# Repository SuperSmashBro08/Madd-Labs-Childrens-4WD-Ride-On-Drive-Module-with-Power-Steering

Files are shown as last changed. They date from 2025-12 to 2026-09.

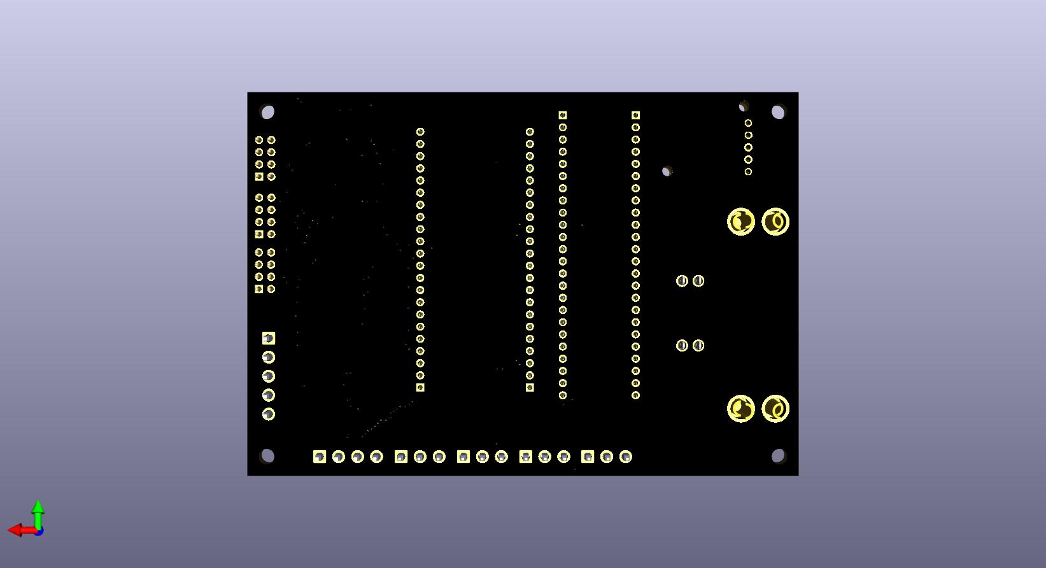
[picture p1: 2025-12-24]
hardware/PCB Files/Kids Ride On PCB Files/Pdfs and images/bottom.jpg

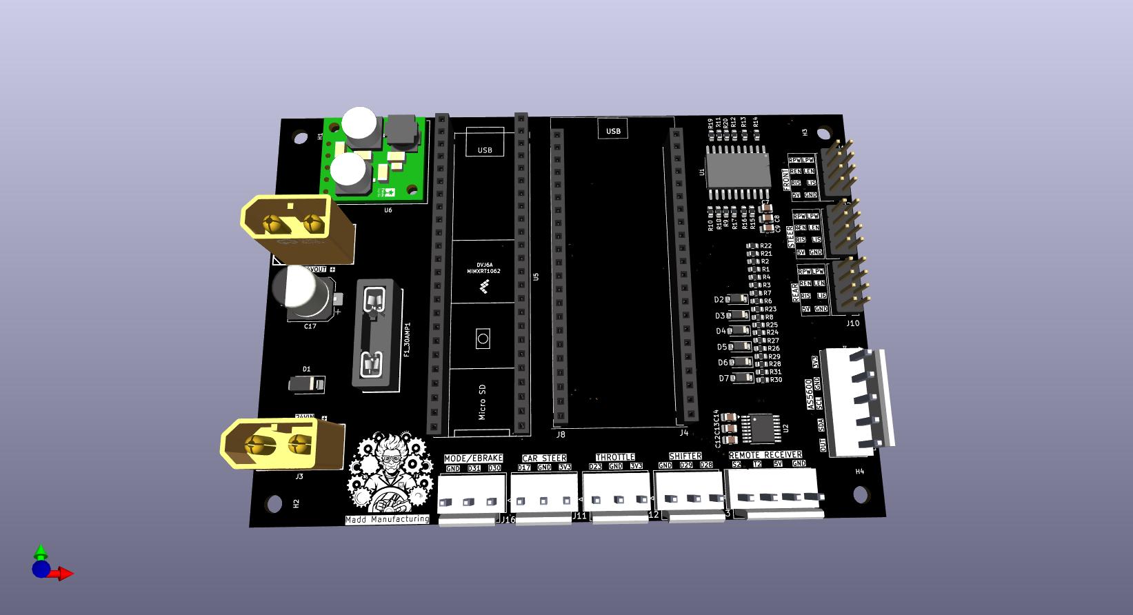
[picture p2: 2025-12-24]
hardware/PCB Files/Kids Ride On PCB Files/Pdfs and images/3d.jpg

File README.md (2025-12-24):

# Kids Ride-On Framework


[]()


An open-source framework for building smart, connected kids' ride-on vehicles with OTA (Over-The-Air) firmware updates, web-based control, and modular peripheral support.

---

## 🎯 Project Overview

This project provides a complete hardware and software framework for upgrading kids' electric ride-on toys with:

- **Dual-MCU Architecture**: ESP32-S3 for WiFi/Web + Teensy 4.1 for real-time control
- **OTA Firmware Updates**: Update both MCUs wirelessly via web browser
- **Web Dashboard**: Monitor and control the vehicle from any device
- **Modular Design**: Easy to add motors, LEDs, sensors, and more
- **Custom PCB**: Purpose-built circuit board for clean integration

---

## 📁 Project Structure

```
Kids-Ride-On-Framework/
├── esp32_flasher/           # ESP32-S3 firmware (WiFi, Web Server, OTA)
│   ├── esp32_flasher.ino    # Main ESP32 code
│   ├── secrets.h.example    # Template for WiFi credentials
│   └── README.md            # ESP32-specific documentation
│
├── teensy_flasherx/         # Teensy 4.1 firmware (Motor control, sensors)
│   ├── teensy_flasherx.ino  # Main application code (YOUR CODE HERE)
│   ├── FlasherXOTA.h/cpp    # OTA update handler (don't modify)
│   ├── FXUtil.h/cpp         # Intel HEX parser (don't modify)
│   ├── FlashTxx.h/c         # Flash primitives (don't modify)
│   └── README.md            # Teensy-specific documentation
│
├── hardware/                # Hardware design files
│   └── PCB/
│       └── Kids Ride On 2.1/
│           ├── Kicad files/ # KiCad schematic and PCB
│           ├── bom/         # Bill of materials
│           ├── 3d/          # 3D models
│           └── Production/  # Gerber files for manufacturing
│
├── Backup/                  # Backup of original firmware
├── readme files/            # Additional documentation
├── .gitignore               # Git ignore rules
└── README.md                # This file
```

---

## 🚀 Getting Started

### Prerequisites

- [Arduino IDE 2.x](https://www.arduino.cc/en/software) or [PlatformIO](https://platformio.org/)
- [Teensyduino](https://www.pjrc.com/teensy/teensyduino.html) add-on for Arduino IDE
- ESP32 Arduino Core (install via Board Manager)

### Hardware Required

- ESP32-S3 DevKitC (or compatible)
- Teensy 4.1
- Custom PCB (see `hardware/PCB/`) or breadboard setup
- 12V/24V power supply (depending on your motors)
- Motors, sensors, LEDs as needed

### Quick Start

1. **Clone the repository**
   ```bash
   git clone https://github.com/yourusername/kids-ride-on-framework.git
   cd kids-ride-on-framework
   ```

2. **Configure WiFi credentials**
   ```bash
   cd esp32_flasher
   cp secrets.h.example secrets.h
   # Edit secrets.h with your WiFi SSID and password
   ```

3. **Upload ESP32 firmware**
   - Open `esp32_flasher/esp32_flasher.ino` in Arduino IDE
   - Select board: ESP32-S3 Dev Module
   - Upload via USB
   - Open Serial Monitor to see the assigned IP address

4. **Upload Teensy firmware**
   - Open `teensy_flasherx/teensy_flasherx.ino` in Arduino IDE
   - Select board: Teensy 4.1
   - Upload via USB (first time only - then use OTA!)

5. **Access the Web Dashboard**
   - Open your browser to the IP address shown in Serial Monitor
   - You can now upload firmware updates wirelessly!

---

## ⚙️ Configuration

### Sensor Calibration (IMPORTANT!)

Every vehicle will have different sensor ranges. Open `teensy_flasherx/teensy_flasherx.ino` and find the **USER CONFIGURATION SECTION** near the top:

```cpp
//******************************************************************************
//                    USER CONFIGURATION SECTION
//******************************************************************************

// ----- STEERING 1 (Primary/Front) -----
#define STEERING1_PIN         A0      // Analog input pin
#define STEERING1_MIN         0       // Raw ADC at full LEFT
#define STEERING1_MAX         1023    // Raw ADC at full RIGHT
#define STEERING1_CENTER      512     // Raw ADC at CENTER

// ----- THROTTLE 1 (Primary) -----
#define THROTTLE1_PIN         A2      // Analog input pin
#define THROTTLE1_MIN         100     // Raw ADC at NO throttle
#define THROTTLE1_MAX         900     // Raw ADC at FULL throttle

// ... more configuration options
```

**How to calibrate:**
1. Upload the firmware with default values
2. Open Serial Monitor
3. Move your steering/throttle and note the raw ADC values
4. Update the MIN/MAX/CENTER values in the code
5. Re-upload (via OTA!)

### WiFi Configuration

For security, WiFi credentials are stored in `secrets.h` which is **not committed to git**.

1. Copy the example file:
   ```bash
   cp esp32_flasher/secrets.h.example esp32_flasher/secrets.h
   ```

2. Edit `secrets.h` with your credentials:
   ```cpp
   #define WIFI_SSID     "YourWiFiName"
   #define WIFI_PASSWORD "YourWiFiPassword"
   ```

---

## 🔧 Hardware

### PCB Design

The custom PCB connects the ESP32-S3 and Teensy 4.1 with proper level shifting and power regulation. Design files are in `hardware/PCB/Kids Ride On 2.1/`.

### Complete Pinout (V2.1 PCB)

#### Teensy 4.1 Pinout

**Analog Inputs (0–3.3V)**
| Pin | Function | Description |
|-----|---|---|
| 17 (A3) | S1_WIPER | Steering Potentiometer |
| 23 (A9) | T1_WIPER | Throttle Potentiometer |
| 16 (A2) | AS5600_OUT | Magnetic Encoder Analog |
| 24 (A10) | STEER_I_L | Steering Motor Current Left |
| 25 (A11) | STEER_I_R | Steering Motor Current Right |
| 26 (A12) | FRONT_I_L | Front Drive Current Left |
| 27 (A13) | FRONT_I_R | Front Drive Current Right |
| 38 (A14) | REAR_I_L | Rear Drive Current Left |
| 39 (A15) | REAR_I_R | Rear Drive Current Right |

**Digital Inputs (3.3V Logic)**
| Pin | Function | Description |
|-----|---|---|
| 28 | SHIFT_FWD | Shifter Forward |
| 29 | SHIFT_REV | Shifter Reverse |
| 30 | MODE_SEL | Mode Select |
| 31 | E_BRAKE | E-Brake Input |

**PWM Outputs (3.3V)**
| Pin | Function | Description |
|-----|---|---|
| 2 | STEER_LPWM | Steering Left PWM |
| 3 | STEER_RPWM | Steering Right PWM |
| 6 | FRONT_LPWM | Front Drive Left PWM |
| 9 | FRONT_RPWM | Front Drive Right PWM |
| 12 | REAR_LPWM | Rear Drive Left PWM |
| 13 | REAR_RPWM | Rear Drive Right PWM |

**Motor Driver Enable (3.3V → 5V via level shifter)**
| Pin | Function | Description |
|-----|---|---|
| 4 | STEER_L_EN | Steering Left Enable |
| 5 | STEER_R_EN | Steering Right Enable |
| 10 | FRONT_L_EN | Front Drive Left Enable |
| 11 | FRONT_R_EN | Front Drive Right Enable |
| 32 | REAR_L_EN | Rear Drive Left Enable |
| 33 | REAR_R_EN | Rear Drive Right Enable |

**I2C (AS5600 Encoder)**
| Pin | Function |
|-----|---|
| 18 | SDA |
| 19 | SCL |

**UART to ESP32-S3**
| Teensy Pin | ESP32 Pin | Function |
|---|---|---|
| 7 (RX2) | GPIO43 (TX) | OTA Flash Data |
| 8 (TX2) | GPIO44 (RX) | OTA Flash Data |
| 14 (TX3) | GPIO18 (RX) | Debug Serial |
| 15 (RX3) | GPIO17 (TX) | Debug Serial |

#### ESP32-S3 Pinout

| GPIO | Function | Description |
|---|---|---|
| 43 | UART TX | TX to Teensy RX2 (Pin 7) |
| 44 | UART RX | RX from Teensy TX2 (Pin 8) |
| 17 | UART TX | TX to Teensy RX3 (Pin 15) |
| 18 | UART RX | RX from Teensy TX3 (Pin 14) |
| 38 | RGB_LED | Status LED / Fiber Optic |

### Bill of Materials

See `hardware/PCB/Kids Ride On 2.1/bom/` for the complete parts list.

---

## 🌐 Web Interface

The ESP32 hosts a web server with:

- **System Status**: Connection status for both MCUs
- **Teensy OTA**: Upload `.hex` files to flash Teensy wirelessly
- **ESP32 OTA**: Upload `.bin` files to update ESP32 wirelessly
- **Serial Monitor**: Real-time serial output from both MCUs

Access via: `http://<ESP32-IP-ADDRESS>/`

---

## 📡 OTA Updates

### Updating Teensy

1. Compile your Teensy code in Arduino IDE
2. Find the `.hex` file in the build folder
3. Open the web dashboard
4. Drag & drop the `.hex` file onto "Flash Teensy 4.1"
5. Wait for completion - Teensy will reboot automatically

### Updating ESP32

1. Export compiled binary from Arduino IDE (Sketch → Export Compiled Binary)
2. Open the web dashboard
3. Drag & drop the `.bin` file onto "ESP32 OTA Update"
4. Wait for completion - ESP32 will reboot automatically

---

## 🛠️ Development

### Adding New Features

All your custom code goes in `teensy_flasherx/teensy_flasherx.ino`:

```cpp
void initPeripherals() {
    // Initialize your motors, LEDs, sensors here
}

void updatePeripherals() {
    // Your main control loop - runs every iteration
    // Read sensors, update motors, etc.
}
```

The FlasherX OTA code is encapsulated and doesn't need modification.

### File Overview

| File | Modify? | Purpose |
|---|---|---|
| `teensy_flasherx.ino` | ✅ YES | Your application code |
| `FlasherXOTA.h/cpp` | ❌ No | OTA update handler |
| `FXUtil.h/cpp` | ❌ No | Intel HEX parser |
| `FlashTxx.h/c` | ❌ No | Low-level flash access |
| `esp32_flasher.ino` | ⚠️ Rarely | Web server & OTA |

---

## 📋 Roadmap

- [x] OTA firmware updates for Teensy 4.1
- [x] OTA firmware updates for ESP32
- [x] Web-based dashboard
- [x] Serial monitor via WebSocket
- [ ] Motor control with acceleration ramping
- [ ] LED strip animations (NeoPixel/WS2812)
- [ ] Steering servo control
- [ ] Speed limiting / parental controls
- [ ] Bluetooth gamepad support
- [ ] Battery monitoring
- [ ] GPS tracking (optional)
- [ ] Mobile app

---

## 🤝 Contributing

Contributions are welcome! Please:

1. Fork the repository
2. Create a feature branch (`git checkout -b feature/amazing-feature`)
3. Commit your changes (`git commit -m 'Add amazing feature'`)
4. Push to the branch (`git push origin feature/amazing-feature`)
5. Open a Pull Request

---

## 📄 License

This project is open source and available under the [MIT License](LICENSE).

---

## ⚠️ Safety Warning

This project involves modifying children's toys with higher-powered electronics. Please:

- Always supervise children when using modified vehicles
- Install appropriate speed limiters
- Use proper fusing and circuit protection
- Test thoroughly in a safe environment
- Follow local regulations for motorized vehicles

---

## 🙏 Acknowledgments

- [FlasherX](https://github.com/joepasquariello/FlasherX) by Joe Pasquariello - Teensy OTA library
- [PJRC](https://www.pjrc.com/) - Teensy development
- [Espressif](https://www.espressif.com/) - ESP32 platform

---

**Happy Building! 🚗💨**

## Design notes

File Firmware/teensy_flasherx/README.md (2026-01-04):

# Teensy 4.1 Kids Ride-On Controller

A comprehensive motor controller firmware for kids' ride-on vehicles featuring dual control modes (steering wheel/pedal and RC remote), safety features, and OTA firmware updates.

## Table of Contents
- [Features](#features)
- [Hardware Overview](#hardware-overview)
- [Control Modes](#control-modes)
- [Safety Features](#safety-features)
- [Configuration Reference](#configuration-reference)
- [Pin Assignments](#pin-assignments)
- [Serial Commands](#serial-commands)
- [OTA Updates](#ota-updates)
- [Troubleshooting](#troubleshooting)

---

## Features

- **Dual Control Modes**: Car mode (steering wheel + pedal) and RC Remote mode (parental override)
- **Rollover Protection**: Speed-based steering limiting and automatic slowdown for sharp turns
- **Soft Stop**: Gradual motor ramp-down to prevent jarring stops on geared motors
- **Encoder Feedback**: Closed-loop steering control using AS5600 magnetic encoder
- **Current Sensing**: Monitor motor current for all 6 motor channels
- **Real-time Telemetry**: Live monitoring via web serial interface
- **OTA Firmware Updates**: Update firmware wirelessly via ESP32-S3 web interface

---

## Hardware Overview

### Microcontroller
- **Teensy 4.1** - 600MHz ARM Cortex-M7
- 10-bit ADC for analog inputs
- I2C for AS5600 encoder
- Multiple UARTs for ESP32 communication

### Motor Drivers (x3)
- **BTS7960** H-Bridge drivers
- Steering motor: Position control with encoder feedback
- Front drive motor: Speed/direction control
- Rear drive motor: Speed/direction control
- 24V power input, 5V enable pins (via level shifter)

### Sensors
- **Steering Pot**: Analog potentiometer on steering column
- **Throttle Pot**: Analog potentiometer on foot pedal
- **AS5600 Encoder**: 12-bit magnetic encoder on steering motor
- **RC Receiver**: PWM signals from RC transmitter

---

## Control Modes

### Mode 1: Car Mode (Default)
The child controls the vehicle using:
- **Steering wheel** → Controls steering motor position
- **Throttle pedal** → Controls front/rear motor speed
- **Shifter** → FWD/REV/NEUTRAL (required for any movement)

**Note**: Steering is disabled in NEUTRAL for safety.

### Mode 2: RC Remote Mode (Parental Override)
The parent takes full control using an RC transmitter:
- **Steer stick (steer2)** → Controls steering (ignores child's steering wheel)
- **Throttle stick (throttle2)** → Controls speed AND direction (ignores shifter)

#### Activating RC Mode
1. Pull RC throttle stick to **full reverse** (≤-90%)
2. **Hold for 3 seconds** → Mode becomes "ARMED"
3. **Release to neutral** → Mode fully activates
4. Serial output: `[RC] *** RC MODE FULLY ACTIVATED ***`

#### Deactivating RC Mode
- Leave **both sticks at neutral** for **20 seconds**
- Mode automatically returns to Car mode
- Serial output: `[RC] *** RC MODE TIMEOUT ***`

**Important**: The "release to neutral" safety prevents accidentally putting the car in reverse when activating RC mode.

---

## Safety Features

### 1. Rollover Protection
Prevents tipping during high-speed turns.

**Part A - Speed-Based Steering Limit:**
| Speed | Max Steering Allowed |
|---|---|
| 0-50% | Full (±100%) |
| 50-80% | Progressively limited |
| 80%+ | Only ±15% |

**Part B - Steering-Based Speed Reduction:**
| Steering Angle | Max Speed Allowed |
|---|---|
| 0-30% | Full (100%) |
| 30-100% | Progressively limited |
| 100% | Only 50% speed |

**How it works**: When you turn sharply, the car slows down FIRST, then allows the turn. This prevents rollovers.

### 2. Soft Stop
Prevents jarring stops when releasing throttle on geared motors.

- Ramps down at **5% per 50ms** (approximately 1 second to stop)
- Acceleration is still immediate (no delay when pressing throttle)
- Direction changes require ramping to zero first

### 3. Neutral Safety
- Steering motor is disabled when shifter is in NEUTRAL
- Prevents unintended steering movement when stationary

### 4. RC Mode Activation Safety
- Requires 3-second hold at full reverse to arm
- Must return to neutral before fully activating
- Prevents accidental reverse when taking control

### 5. RC Mode Timeout
- Automatically returns control to car after 20 seconds of no RC input
- Prevents runaway if parent drops the controller

---

## Configuration Reference

All configurable values are at the top of `teensy_flasherx.ino`.

### Steering Potentiometer (Car's Steering Wheel)
```cpp
#define STEERING_POT_MIN      105     // Raw ADC at full LEFT
#define STEERING_POT_MAX      708     // Raw ADC at full RIGHT  
#define STEERING_POT_CENTER   407     // Raw ADC at CENTER
#define STEERING_POT_DEADZONE 20      // Ignore values within ±20 of center
#define STEERING_INPUT_SMOOTH 15      // Ignore changes < 15% (jitter filter)
#define STEERING_FILTER_ALPHA 0.3     // Low-pass filter (0.0=max filter, 1.0=no filter)
```

### Steering Motor (Encoder-Based Position Control)
```cpp
#define STEER_ANGLE_CENTER    234     // Center angle in degrees
#define STEER_ANGLE_RANGE     45      // ±45° from center (total 90° range)
#define STEER_ANGLE_DEADBAND  15      // Stop motor when within ±15° of target
#define ENCODER_ANGLE_OFFSET  180     // Offset to calibrate encoder zero
```

### Throttle Potentiometer (Foot Pedal)
```cpp
#define THROTTLE_POT_MIN      249     // Raw ADC at NO throttle
#define THROTTLE_POT_MAX      790     // Raw ADC at FULL throttle
#define THROTTLE_POT_DEADZONE 30      // Ignore small values (prevents creep)
```

### RC Receiver (PWM Signals)
```cpp
#define RC_STEER2_PIN         21      // Steering stick input
#define RC_THROTTLE2_PIN      20      // Throttle stick input
```
**Calibrated PWM ranges:**
- Steering: 1065µs (left) → 1500µs (center) → 2000µs (right)
- Throttle: 1000µs (reverse) → 1500µs (neutral) → 2000µs (forward)

### Soft Stop
```cpp
#define SOFT_STOP_RATE        5       // % decrease per step (lower = smoother)
#define SOFT_STOP_INTERVAL    50      // Milliseconds between steps
```
**Tuning**: For slower/smoother stops, decrease RATE to 3 or 2. For faster stops, increase to 8 or 10.

### Rollover Protection
```cpp
#define ROLLOVER_PROTECTION_ENABLED  true   // Master enable (set false to disable)
#define ROLLOVER_SPEED_THRESHOLD     50     // Speed % where limiting starts
#define ROLLOVER_SPEED_FULL_LIMIT    80     // Speed % where max limit applies
#define ROLLOVER_MIN_STEER_RANGE     15     // Min steering % at high speed
#define ROLLOVER_SLOWDOWN_ANGLE      30     // Steer % where speed reduction starts
#define ROLLOVER_SLOWDOWN_FACTOR     50     // Max speed % at full steering
```

**Tuning Guide:**
| Want to... | Adjust |
|---|---|
| Allow more steering at high speed | Increase `ROLLOVER_MIN_STEER_RANGE` |
| Start limiting earlier | Decrease `ROLLOVER_SPEED_THRESHOLD` |
| Slow down more for turns | Decrease `ROLLOVER_SLOWDOWN_FACTOR` |
| Start slowing earlier | Decrease `ROLLOVER_SLOWDOWN_ANGLE` |

### Motor Configuration
```cpp
#define MOTOR_PWM_FREQ        20000   // PWM frequency (Hz)
#define MOTOR_MAX_SPEED       255     // Max PWM value (0-255)
```

---

## Pin Assignments

### Analog Inputs
| Pin | Function |
|-----|---|
| 17 (A3) | Steering Pot |
| 23 (A9) | Throttle Pot |
| 20 (A6) | RC Throttle2 |
| 21 (A7) | RC Steer2 |
| 24-27, 38-39 | Current Sensors |

### Digital Inputs
| Pin | Function |
|-----|---|
| 28 | Shifter Reverse |
| 29 | Shifter Forward |
| 30 | Mode Select |
| 31 | E-Brake |

### PWM Outputs (Motor Drivers)
| Pins | Motor |
|---|---|
| 2, 3 | Steering LPWM/RPWM |
| 6, 9 | Front LPWM/RPWM |
| 12, 13 | Rear LPWM/RPWM |

### Enable Outputs (via Level Shifter)
| Pins | Motor |
|---|---|
| 4, 5 | Steering L_EN/R_EN |
| 10, 11 | Front L_EN/R_EN |
| 32, 33 | Rear L_EN/R_EN |

### I2C (Encoder)
| Pin | Function |
|-----|---|
| 18 | SDA |
| 19 | SCL |

### UART (ESP32)
| Pins | Function |
|---|---|
| 7, 8 | Serial2 (OTA Flash) |
| 14, 15 | Serial3 (Telemetry) |

---

## Serial Commands

Connect via USB Serial at 115200 baud.

| Command | Description |
|---|---|
| `help` | Show all commands |
| `status` | Show system status |
| `version` | Show firmware version |
| `telem` or `t` | Toggle telemetry on/off |
| `header` or `h` | Print telemetry header |
| `verbose` or `v` | Verbose telemetry mode |
| `compact` or `c` | Compact telemetry mode |
| `rate <ms>` | Set telemetry rate (10-1000ms) |
| `rctest` or `rc` | Test RC receiver PWM signals |
| `calenc` or `ce` | Encoder calibration helper |

---

## Telemetry Output

The telemetry displays real-time data in the web serial monitor:

```
|------- RAW INPUTS ------|--- PROCESSED (%) ---|-- PWM OUTPUTS --|--- CURRENT ---|SOURCE|-- SYS --|
| Steer Throt Str2  Thr2  Encdr | Steer Throt Str2  Thr2  | StL  StR  FrL  FrR  ReL  ReR| ...      |      | Loop  T |
```

**Columns:**
- **RAW INPUTS**: Steering pot, Throttle pot, RC steer, RC throttle, Encoder angle
- **PROCESSED**: Converted to -100% to +100% or 0-100%
- **PWM OUTPUTS**: Current PWM values for all 6 motor channels
- **CURRENT**: Motor current in mA (if sensors calibrated)
- **SOURCE**: "Car" or "Remot" (which input is active)
- **SYS**: Loop time (µs) and CPU temperature

---

## OTA Updates

Firmware can be updated wirelessly via the ESP32-S3 web interface.

### How It Works
1. ESP32 hosts a web page with file upload
2. User uploads `.hex` file from Arduino IDE
3. ESP32 sends firmware to Teensy via Serial2
4. Teensy writes to flash buffer and reboots

### To Generate .hex File
In Arduino IDE: Sketch → Export Compiled Binary

---

## Troubleshooting

| Issue | Solution |
|---|---|
| Motors don't move | Check EN pins going HIGH, verify shifter not in NEUTRAL |
| Steering oscillates | Increase `STEER_ANGLE_DEADBAND`, check encoder wiring |
| Steering jitters | Increase `STEERING_INPUT_SMOOTH`, decrease `STEERING_FILTER_ALPHA` |
| RC mode won't activate | Hold throttle full reverse 3+ seconds, then release to neutral |
| Car tips over in turns | Decrease `ROLLOVER_MIN_STEER_RANGE` and `ROLLOVER_SLOWDOWN_FACTOR` |
| Stops too abruptly | Decrease `SOFT_STOP_RATE` to 2 or 3 |
| RC reading 0 | Use `rctest` command to check PWM signals, verify wiring |

---

## Version History

- **1.5.3** - Rollover protection, soft stop, RC mode improvements
- **1.5.x** - RC receiver PWM support, source display
- **1.4.x** - Encoder-based steering control
- **1.3.x** - Initial motor control implementation

---

## License

This project is open source. See LICENSE file for details.

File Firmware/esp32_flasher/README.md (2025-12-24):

# ESP32-S3 Teensy 4.1 FlasherX Web Interface

A web-based firmware upload system for programming Teensy 4.1 via an ESP32-S3 using the FlasherX protocol.

## Features

- **Teensy 4.1 Flashing**: Upload .hex/.bin firmware files via FlasherX protocol
- **ESP32 OTA Updates**: Update the ESP32 firmware over-the-air
- **Web Interface**: Modern responsive UI at http://192.168.1.29
- **Upload Progress Bar**: Real-time progress indication
- **Error Reporting**: Clear error messages for troubleshooting
- **Serial Monitor**: Live serial output from both ESP32 and Teensy via WebSocket

## Hardware Requirements

- ESP32-S3 DevKit
- Teensy 4.1
- Custom PCB with pre-wired UART connections

## Custom PCB Wiring

### Flashing UART (ESP32 UART0 ↔ Teensy Serial2)
Used for firmware upload via FlasherX protocol.

| ESP32-S3 Pin | Teensy 4.1 Pin | Function |
|---|---|---|
| GPIO 43 (TX0) | RX2 (Pin 7) | ESP32 TX → Teensy RX |
| GPIO 44 (RX0) | TX2 (Pin 8) | ESP32 RX ← Teensy TX |

### Debug UART (ESP32 UART1 ↔ Teensy Serial3)
Used for serial monitoring in web interface.

| ESP32-S3 Pin | Teensy 4.1 Pin | Function |
|---|---|---|
| GPIO 17 | RX3 (Pin 15) | ESP32 TX → Teensy RX |
| GPIO 18 | TX3 (Pin 14) | ESP32 RX ← Teensy TX |

### Control Pins
| ESP32-S3 Pin | Teensy 4.1 Pin | Function |
|---|---|---|
| GPIO 4 | Reset | Reset control |
| GPIO 5 | Program | Program mode |
| GND | GND | Ground |

## Configuration

Edit the following in `esp32_flasher.ino`:

```cpp
const char* ssid = "YOUR_SSID";
const char* password = "YOUR_PASSWORD";
```

## Arduino IDE Setup

### Board Manager
1. Add ESP32 board URL: `https://raw.githubusercontent.com/espressif/arduino-esp32/gh-pages/package_esp32_index.json`
2. Install "ESP32 by Espressif Systems"

### Library Dependencies
Install via Library Manager:
- **ArduinoJson** by Benoit Blanchon (v6.x)
- **WebSockets** by Markus Sattler

### Board Settings
- Board: "ESP32S3 Dev Module"
- USB Mode: "USB-OTG (TinyUSB)"
- Partition Scheme: "Default 4MB with spiffs"
- Upload Speed: 921600

## Usage

1. Upload this sketch to ESP32-S3
2. Open Serial Monitor (115200 baud) to see connection status
3. Navigate to http://192.168.1.29 in your browser
4. Use the web interface to:
   - Upload Teensy firmware (.hex or .bin files)
   - Update ESP32 firmware via OTA (.bin files)
   - Monitor serial output from both devices
   - Reset Teensy remotely

## FlasherX Protocol

The Teensy must have the FlasherX receiver sketch loaded. The protocol uses:
- **Flash Serial (Serial2)**: Firmware data transfer
- **Debug Serial (Serial3)**: Status messages to web monitor

Protocol commands:
- Sync: Send 0x55 bytes, receive ACK (0x06)
- Block: Send address + data + checksum, receive ACK
- Finish: Send finish command, receive ACK

## Troubleshooting

| Issue | Solution |
|---|---|
| WiFi won't connect | Check SSID/password, verify 2.4GHz network |
| FlasherX sync fails | Verify wiring, check Teensy has receiver sketch |
| Upload progress stuck | Check serial connection speed (115200 baud) |
| WebSocket disconnects | Refresh page, check network stability |

## LED Indicators (Web UI)

- 🟢 Green: Connected/Success
- 🔴 Red: Disconnected/Error
- 🔵 Blue: In Progress

## API Endpoints

| Endpoint | Method | Description |
|---|---|---|
| `/` | GET | Web interface |
| `/status` | GET | System status JSON |
| `/teensy/upload` | POST | Upload Teensy firmware |
| `/teensy/reset` | POST | Reset Teensy |
| `/esp/ota` | POST | ESP32 OTA update |

WebSocket on port 81 for real-time serial monitoring.

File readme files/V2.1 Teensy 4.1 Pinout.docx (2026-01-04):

# Kids Ride-On V3 – Teensy 4.1 & ESP32-S3 Pinout

## Teensy 4.1 Pinout

### Analog Inputs (0–3.3V)

- Pin 17 (A3) – Steering Pot (S1_WIPER)
- Pin 23 (A9) – Throttle Pot (T1_WIPER)
- Pin 16 (A2) – AS5600 Analog Out
- Pin 24 (A10) – Steer Motor Current L
- Pin 25 (A11) – Steer Motor Current R
- Pin 26 (A12) – Front Drive Current L
- Pin 27 (A13) – Front Drive Current R
- Pin 38 (A14) – Rear Drive Current L
- Pin 39 (A15) – Rear Drive Current R

### Digital Inputs (3.3V Logic)

- Pin 28 – Shifter Forward
- Pin 29 – Shifter Reverse
- Pin 30 – Mode Select
- Pin 31 – E-Brake Input

### PWM Outputs (3.3V)

- Pin 2 – Steering LPWM
- Pin 3 – Steering RPWM
- Pin 6 – Front Drive LPWM
- Pin 9 – Front Drive RPWM
- Pin 12 – Rear Drive LPWM
- Pin 13 – Rear Drive RPWM

### Motor Driver Enable Outputs (3.3V → 5V)

- Pin 4 – Steering L_EN
- Pin 5 – Steering R_EN
- Pin 10 – Front Drive L_EN
- Pin 11 – Front Drive R_EN
- Pin 32 – Rear Drive L_EN
- Pin 33 – Rear Drive R_EN

### I2C

- Pin 18 – SDA
- Pin 19 – SCL

### UART Links to ESP32-S3

- Pin 8 (TX2) → ESP32 GPIO44
- Pin 7 (RX2) ← ESP32 GPIO43
- Pin 14 (TX3) → ESP32 GPIO18
- Pin 15 (RX3) ← ESP32 GPIO17

## ESP32-S3 Used Pins

- GPIO44 – UART RX from Teensy TX2
- GPIO43 – UART TX to Teensy RX2
- GPIO18 – UART RX from Teensy TX3
- GPIO17 – UART TX to Teensy RX3
- GPIO38 – RGB / Fiber Optic Status Indicator

## Remote Control Pins 5V

- GPIO 20 – Steering2
- GPIO 21 –Throttle2

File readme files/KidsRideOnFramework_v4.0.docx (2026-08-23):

# MAD LABS – Kids Ride-On 24 V Control System

## Architecture & Safety Framework

Project: Kids Ride-On 24 V 4WD

Maintainer: MAD Labs / MAD Manufacturing

Baseline Version: v4.0

Status: Active / Living Document

## 1. Purpose of This Document

This file defines the high-level architecture, responsibilities, and safety philosophy of the MAD Labs Kids Ride-On control system.

It is intentionally implementation-agnostic: - No firmware code - No low-level wiring diagrams - No PCB schematics

Those details live elsewhere (pinout docs, KiCad, firmware repos).

This document answers: - What each subsystem does - How power and control are structured - Where safety decisions are made - Why the system is designed this way

This is a living, append-only framework. New safety features or behavioral rules are added as sections, not replacements.

## 2. Power Architecture

- 24 V Battery Input
  - Primary system power
  - Routed directly to all motor drivers
- Logic Power (5 V)
  - Derived from 24 V via buck converter
  - Supplies:
    - Teensy 4.1
    - ESP32-S3
    - Motor driver logic pins
- Separation of Domains
  - High-current motor power remains isolated from logic control
  - Logic ground is common-reference only

## 3. Controller Roles & Separation of Concerns

### 3.1 Teensy 4.1 — Real-Time Control Controller

The Teensy 4.1 is the authoritative control brain of the vehicle.

Responsibilities: - All PWM motor control - All sensor acquisition - All safety logic - Closed-loop steering control - Soft-start / soft-stop behavior - Speed vs steering angle limiting - Fault detection and response

All sensors connect directly to the Teensy.

No safety-critical decision depends on the ESP32.

### 3.2 ESP32-S3 — OTA & Monitoring Hub

The ESP32-S3 exists to remove the need for physical access to the system.

Responsibilities: - Over-the-air firmware updates (ESP32 + Teensy) - High-speed serial monitoring - Web / OTA hub connectivity - System status indication (RGB)

The ESP32 does not: - Generate PWM - Read safety sensors - Make motion decisions

A failure of the ESP32 does not prevent safe vehicle operation.

## 4. Inter-Processor Communication

- Two dedicated UART links between Teensy and ESP32
  - UART A: Teensy firmware flashing
  - UART B: High-speed telemetry / logging
- ESP32 acts as:
  - Uploader
  - Bridge
  - Monitor

## 5. Motor Control Architecture

Three independent motor groups are controlled via BTS7960 drivers:

### 5.1 Steering Motor

- Electrically actuates steering
- Closed-loop control using magnetic encoder feedback
- Software-defined soft limits

### 5.2 Front Drive Motors

- Both front wheels driven together
- Current sensing monitored
- PWM speed control

### 5.3 Rear Drive Motors

- Both rear wheels driven together
- Current sensing monitored
- PWM speed control

All motor groups: - Use PWM for speed - Use enable pins for safety gating - Are monitored for overcurrent conditions

## 6. Sensors & User Inputs

### 6.1 Magnetic Steering Encoder

- Absolute angle measurement
- Used for:
  - Closed-loop steering
  - Steering angle limits
  - Speed to Steering Angle-based safety reduction

### 6.2 Throttle Input

- Analog potentiometer
- Represents user-requested speed

### 6.3 Steering Input

- Analog potentiometer
- User-requested steering direction

### 6.4 Shifter

- Neutral / Forward / Reverse
- Neutral enforced during fault conditions

### 6.5 Mode / E-Brake (Reserved)

- Future expansion input
- Intended for advanced safety or braking modes.. but this is not actually implemented in code and can be used for anything you desire ie does not have to be for e-brake or mode

### 6.6 Remote Control (Parental Override)

- Allows adult takeover of vehicle control

Takeover Procedure: 1. Hold Down + Reverse for 3 seconds 2. Return controls to neutral 3. Remote gains control 4. Control auto-releases after 20 seconds of inactivity

## 7. Motion Behavior & Safety Logic

### 7.1 Soft Start / Soft Stop

- Acceleration is ramped
- Deceleration is ramped
- Prevents sudden jolts
- Reduces drivetrain stress
- Must include during Takeover Procedure(prevents sudden stop on takeover if vehicle is moving fast)

### 7.2 Steering Angle vs Speed Limiting

- Maximum steering angle decreases as speed increases
- If a sharp steering angle is requested:
  - Vehicle speed is reduced first
  - Steering is then allowed

This reduces rollover risk but does not eliminate it.

## 8. System Status Indicator

### RGB Indicator (ESP32 GPIO38)

- Fiber-optic RGB output
- Always illuminated

Indicator States: - RED (Default) - ESP32 not connected - Teensy not responding - OTA server unavailable

- GREEN pulsing
  - ESP32 online
  - Teensy responding
  - OTA server reachable
- BLUE pulsing
  - OTA Updating in Progress

This provides an immediate visual health indicator.

## 9. Connector Philosophy (High Level)

- Motor drivers use multi-pin locking connectors
- Sensors use grouped, keyed connectors
- Future expansion ports are reserved and documented

Exact pin mappings are defined in the PCB pinout documentation.

## 10. Failure Modes & Responses (Why This Exists)

This section is intentionally high-level.

It does not list every fault condition.

Instead, it defines the rule:

Any detected fault must move the system to a safer state than it was previously in.

Examples: - Loss of Steering1 or angle sense feedback → cut Throttle1 - Overcurrent detected → reduce PWM or disable output - Invalid input state → force neutral

As new safety behaviors are added, they are appended here as subsections.

## 11. Living Document Policy

- This file is versioned in GitHub
- New features append sections
- Existing sections are not rewritten without version notes

This creates a clear historical record of why the system behaves the way it does.

End of Baseline Framework (v4.0)

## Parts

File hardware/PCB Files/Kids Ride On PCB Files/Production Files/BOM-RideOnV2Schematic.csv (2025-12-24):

Comment | Designator | Footprint | LCSC | Quantity
0R | R32 | R_0805_2012Metric | C100045 | 1
3.3k | R24,R26,R28,R30,R7,R8 | R_0603_1608Metric | C108078 | 6
33R | R1,R15,R16,R17,R18,R19,R2,R20,R21,R22,R3,R4 | R_0603_1608Metric | C108661 | 12
10uF | C14,C9 | C_0805_2012Metric | C15850 | 2
Conn_01x03 | J11,J12,J13,J16 | JST_VH_B3P-VH-B_1x03_P3.96mm_Vertical | C160316 | 4
Conn_01x04 | J5 | JST_VH_B4P-VH-B_1x04_P3.96mm_Vertical | C160317 | 1
Conn_01x05 | J7 | JST_VH_B5P-VH-B_1x05_P3.96mm_Vertical | C160318 | 1
1.8k | R23,R25,R27,R29,R31,R6 | R_0603_1608Metric | C185354 | 6
SN74AHCT244 | U1 | SOIC-20_L12.8-W7.5-P1.27-LS10.3-BL | C2675568 | 1
1uF | C13,C8 | C_0805_2012Metric | C28323 | 2
Conn_01x24 | J6,J9 | PinSocket_1x24_P2.54mm_Vertical | C2883741 | 2
Conn_02x04_Odd_Even | J1,J10,J2 | PinHeader_2x04_P2.54mm_Vertical | C32713277 | 3
Fuse | F1_30AMP1 | FUSE-TH_4P-L19.8-W6.7_3557-2 | C352820 | 1
CD74HC4050 | U2 | TSSOP-16_4.4x5mm_P0.65mm | C352825 | 1
SMAJ33A | D1 | D_SMA | C353454 | 1
3.4V | D2,D3,D4,D5,D6,D7 | D_SOD-123 | C48587220 | 6
100nF | C12,C7 | C_0805_2012Metric | C49678 | 2
220uF/35V | C17 | CP_Elec_8x10.5 | C5246556 | 1
Conn_01x22 | J4,J8 | PinSocket_1x22_P2.54mm_Vertical | C7499337 | 2
10k | R10,R11,R12,R13,R14,R9 | R_0603_1608Metric | C98220 | 6
XT60-M. | J15,J3 | CONN-TH_XT60 | C98733 | 2
D24V50F5 | U6 | D24V50F5 |  | 1

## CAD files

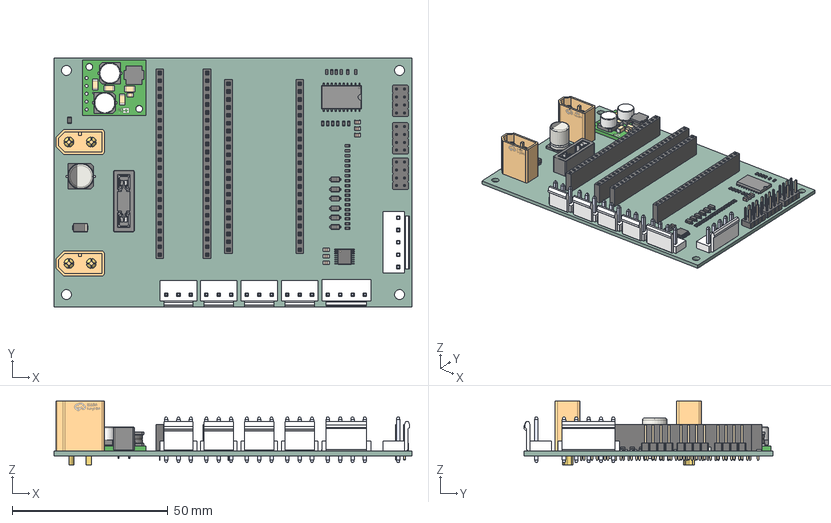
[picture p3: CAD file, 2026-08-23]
hardware/PCB Files/Kids Ride On PCB Files/3d/RideOnSchematic.step
115.0 x 80.0 x 20.5 mm
R_0603_1608Metric x 30
d24v50f5-step-down-voltage-regulator
C_0805_2012Metric x 6
PinHeader_2x04_P2.54mm_Vertical x 3
D_SOD-123 x 6
BxP-VH_4
pin x 4
R_0805_2012Metric
CP_Elec_8x10.5
TSSOP-16_4.4x5mm_P0.65mm
PinSocket_1x24_P2.54mm_Vertical x 2
FUSE-TH_4P-L19.8-W6.7_3557-2
CONN-TH_XT60 x 2
B3P-VH(LF)(SN)_B3P-VH(LF)(SN) x 4
SOIC-20_L12.8-W7.5-P1.27-LS10.3-BL
D_SMA
PinSocket_1x22_P2.54mm_Vertical x 2
B5P-VH-LF--SN---3DModel-STEP-269445
RideOnV2Schematic_PCB

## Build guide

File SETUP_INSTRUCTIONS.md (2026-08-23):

# Kids Custom Power Wheels Project - Setup Instructions

## Table of Contents
1. [Required Parts & Tools](#required-parts--tools)
2. [Firmware Setup](#firmware-setup)
3. [Hardware Assembly](#hardware-assembly)
4. [Wiring Guide](#wiring-guide)
5. [First Power-Up](#first-power-up)

---

## Required Parts & Tools

### Electronics
| Qty | Part | Description |
|-----|---|---|
| 1 | Teensy 4.1 | Main microcontroller |
| 1 | ESP32-S3 DevKitC-1 (N8R8) | WiFi/Web server controller from Espressif |
| 3 | BTS7960 Motor Driver Modules | High-current H-bridge motor drivers (Steering, Front, Rear) |
| 1 | Pololu D24V50F5 | 5V 5A Step-down voltage regulator |
| 1 | AS5600 Encoder Module | Magnetic rotary encoder for steering feedback |
| 1 | FlySky FS-i6X | RC controller with receiver |
| 1 | Custom PCB | Main control board |

### Connectors & Hardware
| Qty | Part | Description |
|-----|---|---|
| 4 | XT60E-M | Panel mount male connectors |
| 6 | XT60 Female | Female bullet connectors |
| 8 | JST-VH 3.96mm 3-pin Female | For BTS7960 signal connections |
| 4 | JST-VH 3.96mm 3-pin Male | Mating connectors |
| 2 | JST-VH 3.96mm 4-pin Female | For additional connections |
| 1 | JST-VH 3.96mm 4-pin Male | Mating connector |
| 2 | JST-VH 3.96mm 5-pin Female | For receiver connection |
| 1 | JST-VH 3.96mm 5-pin Male | Mating connector |
| 1 | 30-40A Blade Fuse | Main power protection |
| 6 | M3x20mm Standoffs | PCB mounting (or 3D printed) |
| - | M3 Screws | Various lengths for assembly |
| - | M2.5 Screws | For XT60E-M connector mounting |
| - | Spade Connectors | For shifter connections |
| - | Dupont Connector Assortment | For misc connections |
| - | Heat Shrink Assortment | Wire insulation |

### Wire
| Qty | Part | Description |
|-----|---|---|
| - | 16 AWG Red Wire | Power positive connections |
| - | 16 AWG Black Wire | Power ground connections |

### Controls
| Qty | Part | Description |
|-----|---|---|
| 1 | Foot Pedal Potentiometer | Throttle control (Amazon) |
| 1 | Waterproof Potentiometer | Steering wheel feedback |
| 1-2 | 3-Way Rocker Switch | For shifter (if not using existing) |

### Tools Required
- Soldering station
- Wire cutters/strippers
- Crimping tools (for JST and Dupont connectors)
- Screwdrivers
- Multimeter (recommended)

---

## Firmware Setup

### Step 1: Configure WiFi Credentials

1. Navigate to the `Firmware/esp32_flasher/` folder
2. Open the `secrets.h` file
3. Add your WiFi network credentials:

```cpp
#define WIFI_SSID "YourWiFiNetworkName"
#define WIFI_PASSWORD "YourWiFiPassword"
```

4. Save the file

### Step 2: Flash the ESP32-S3

1. Connect the ESP32-S3 DevKitC-1 to your computer via USB
2. Open the Arduino IDE (or PlatformIO)
3. Select the correct board: **ESP32-S3 Dev Module**
4. Select the correct COM port
5. Open `Firmware/esp32_flasher/esp32_flasher.ino`
6. Click **Upload** to flash the firmware
7. **Important:** Open the Serial Monitor and set the baud rate to **115200**
8. The ESP32 will display its IP address once connected to your WiFi network
9. **Write down this IP address** - you will need it to access the web server

### Step 3: Flash the Teensy 4.1

1. Connect the Teensy 4.1 to your computer via USB
2. Open the Arduino IDE with Teensyduino installed
3. Select board: **Teensy 4.1**
4. Select the correct COM port
5. Open `Firmware/teensy_flasherx/teensy_flasherx.ino`
6. Click **Upload** to flash the firmware
7. Wait for the upload to complete

### Step 4: Access the Web Server

1. Open a web browser on a device connected to the same WiFi network
2. Type the IP address from Step 2 into the browser address bar
3. The web interface should load, allowing you to configure and control the system

---

## Hardware Assembly

### PCB Mounting

1. Install the 6x M3x20mm standoffs (or 3D printed standoffs) to mount the custom PCB in the enclosure
2. Secure with M3 screws

### Install the Fuse

1. Insert the **30-40A blade fuse** into the fuse slot on the custom PCB
2. Ensure it is fully seated

### Install the Voltage Regulator

1. Mount the Pololu D24V50F5 step-down regulator to the designated location on the PCB
2. This converts the 24-27V input to 5V for the control electronics

### Install Microcontrollers

1. Plug the **Teensy 4.1** into its designated socket on the custom PCB
2. Plug the **ESP32-S3 DevKitC-1** into its designated socket on the custom PCB
3. Ensure both are properly oriented and fully seated

### Mount XT60E-M Connectors

1. Install the 4x XT60E-M panel mount connectors in the enclosure
2. Secure with M2.5 screws

---

## Wiring Guide

### Power Input

1. Connect **24V to 27V** power source to the main power input
2. Use 16 AWG wire for all power connections
3. **Red = Positive (+)**
4. **Black = Negative/Ground (-)**

### BTS7960 Motor Driver Wiring

You have **3x BTS7960 modules** controlling:
- **Steering Motor**
- **Front Drive Motor**
- **Rear Drive Motor**

#### Power Connections (for each BTS7960):
| BTS7960 Pin | Connection |
|---|---|
| B+ | 24-27V Positive (from PCB power out) |
| B- | Ground (from PCB power out) |
| M+ | Motor Positive |
| M- | Motor Negative |

Use **16 AWG red and black wire** for all power in/out connections to the BTS7960 modules.

#### Signal Connections (8-pin JST):

Each BTS7960 module has an 8-pin signal connection to the custom PCB.

**The pins are clearly labeled on both the BTS7960 module and the custom PCB - simply match the labels:**

| Pin | Signal |
|-----|---|
| RPWM | Right PWM |
| LPWM | Left PWM |
| R_EN | Right Enable |
| L_EN | Left Enable |
| R_IS | Right Current Sense |
| L_IS | Left Current Sense |
| VCC | 5V Logic |
| GND | Ground |

Use the 3-pin JST-VH connectors to connect from the custom PCB to each BTS7960 module.

### FlySky Receiver Wiring

Connect the FlySky receiver to the custom PCB using the JST connector:

| Receiver Pin | PCB Connection |
|---|---|
| 5V (VCC) | 5V |
| GND | GND |
| CH1 (Steering) | Steering Signal Pin |
| CH2 (Throttle) | Throttle Signal Pin |

### AS5600 Encoder Wiring

Connect the AS5600 magnetic encoder module for steering position feedback according to the PCB pinout.

### Shifter Wiring

**If your Power Wheels has an existing shifter:**
- Connect the shifter contacts to the PCB using spade connectors

**If you need to build a shifter:**
- Use 2x 3-way rocker switches
- Wire to provide Forward/Neutral/Reverse selection

### Throttle Pedal

Connect the foot pedal potentiometer:
- VCC → 5V
- GND → Ground  
- Signal → Throttle ADC input

### Steering Wheel Potentiometer

Connect the waterproof potentiometer on the steering wheel:
- VCC → 5V
- GND → Ground
- Signal → Steering ADC input

---

## First Power-Up

### Pre-Power Checklist

- [ ] All wiring double-checked
- [ ] Fuse installed (30-40A)
- [ ] Both Teensy and ESP32 are flashed and installed
- [ ] BTS7960 modules connected (power and signal)
- [ ] FlySky receiver connected
- [ ] Motors connected to BTS7960 outputs
- [ ] No loose wires or short circuits

### Power On Sequence

1. Ensure the FlySky transmitter is **OFF**
2. Apply **24-27V** power to the system
3. Wait for the ESP32 to boot and connect to WiFi
4. Open Serial Monitor at **115200 baud** to verify IP address (if needed)
5. Access the web interface via the IP address in your browser
6. Turn on the FlySky transmitter
7. Verify communication in the web interface
8. Test each function at low power before full operation

### Troubleshooting

| Issue | Solution |
|---|---|
| No IP address displayed | Check WiFi credentials in `secrets.h` |
| Web server not loading | Ensure device is on same network, check IP address |
| Motors not responding | Check BTS7960 wiring, verify 8-pin signal connections |
| No RC signal | Verify FlySky receiver wiring, check binding |
| System not powering on | Check fuse, verify voltage (24-27V) |

---

## Safety Warnings

⚠️ **CAUTION:** This system operates at high currents. Always:
- Use appropriately rated wire (16 AWG minimum for power)
- Install the fuse before first power-up
- Double-check polarity before connecting power
- Supervise children at all times during operation
- Test in a safe, open area

---

## Support

For questions, issues, or contributions, please open an issue on the GitHub repository.

**Happy Building!** 🚗⚡

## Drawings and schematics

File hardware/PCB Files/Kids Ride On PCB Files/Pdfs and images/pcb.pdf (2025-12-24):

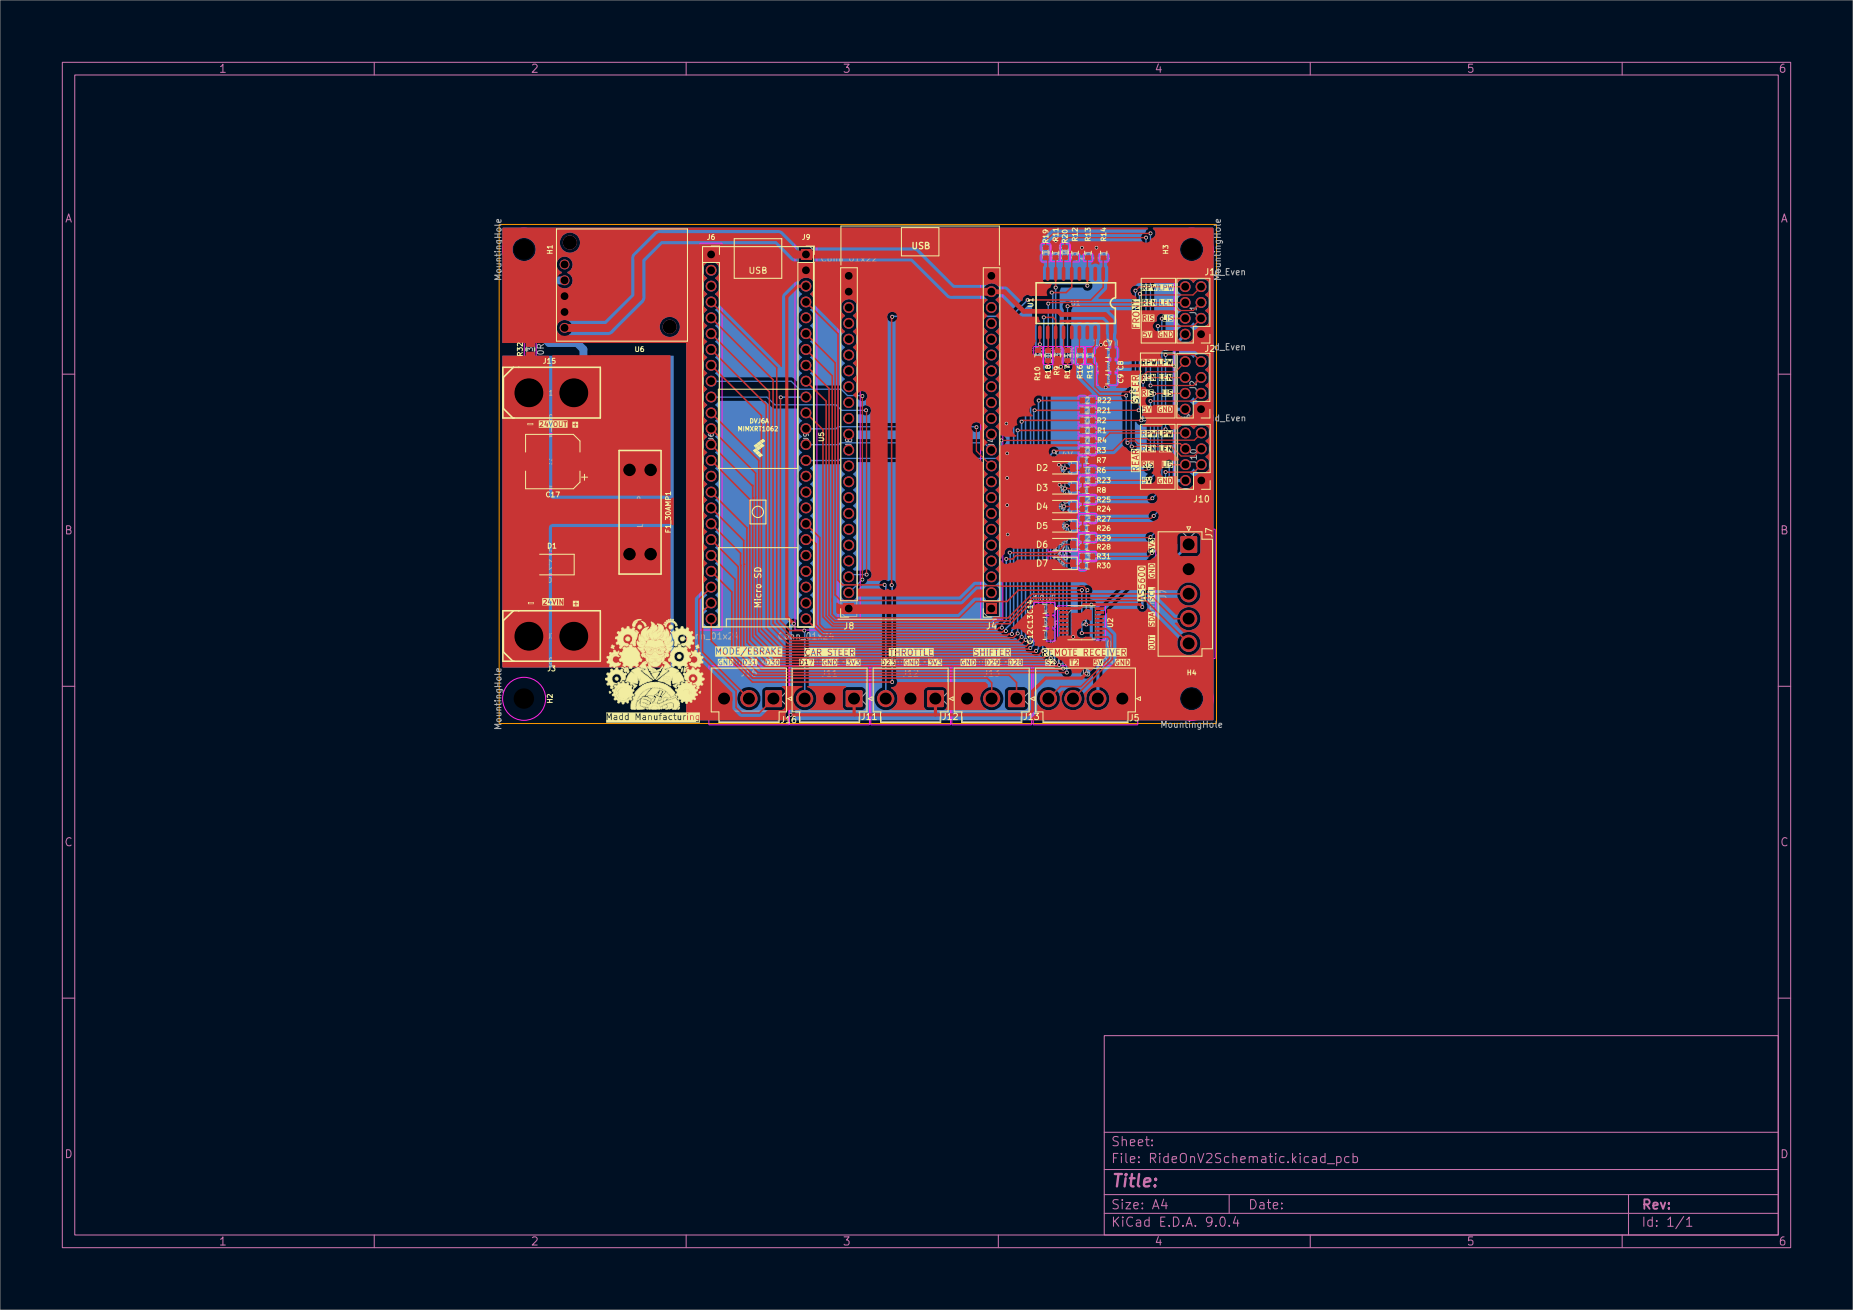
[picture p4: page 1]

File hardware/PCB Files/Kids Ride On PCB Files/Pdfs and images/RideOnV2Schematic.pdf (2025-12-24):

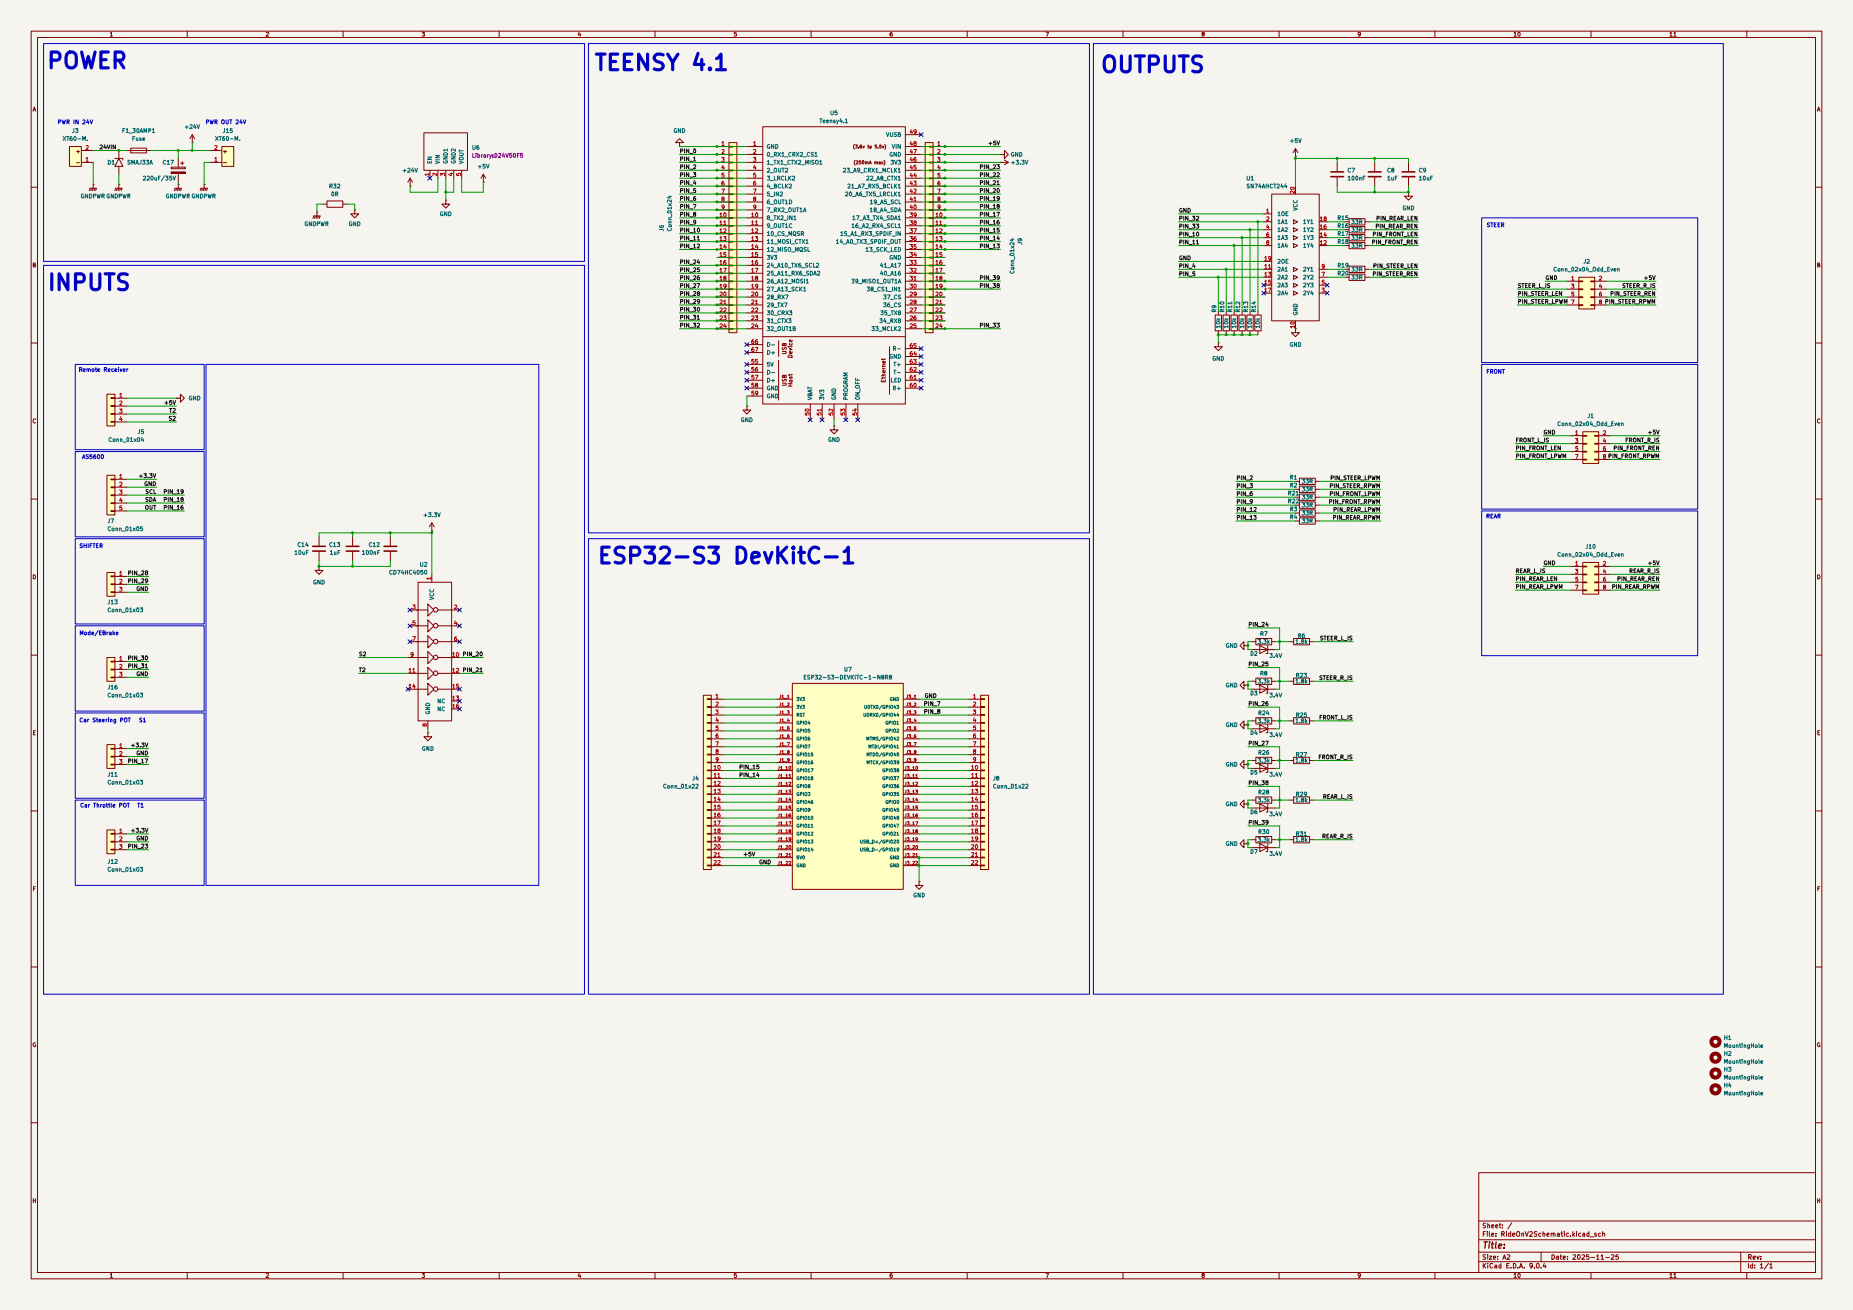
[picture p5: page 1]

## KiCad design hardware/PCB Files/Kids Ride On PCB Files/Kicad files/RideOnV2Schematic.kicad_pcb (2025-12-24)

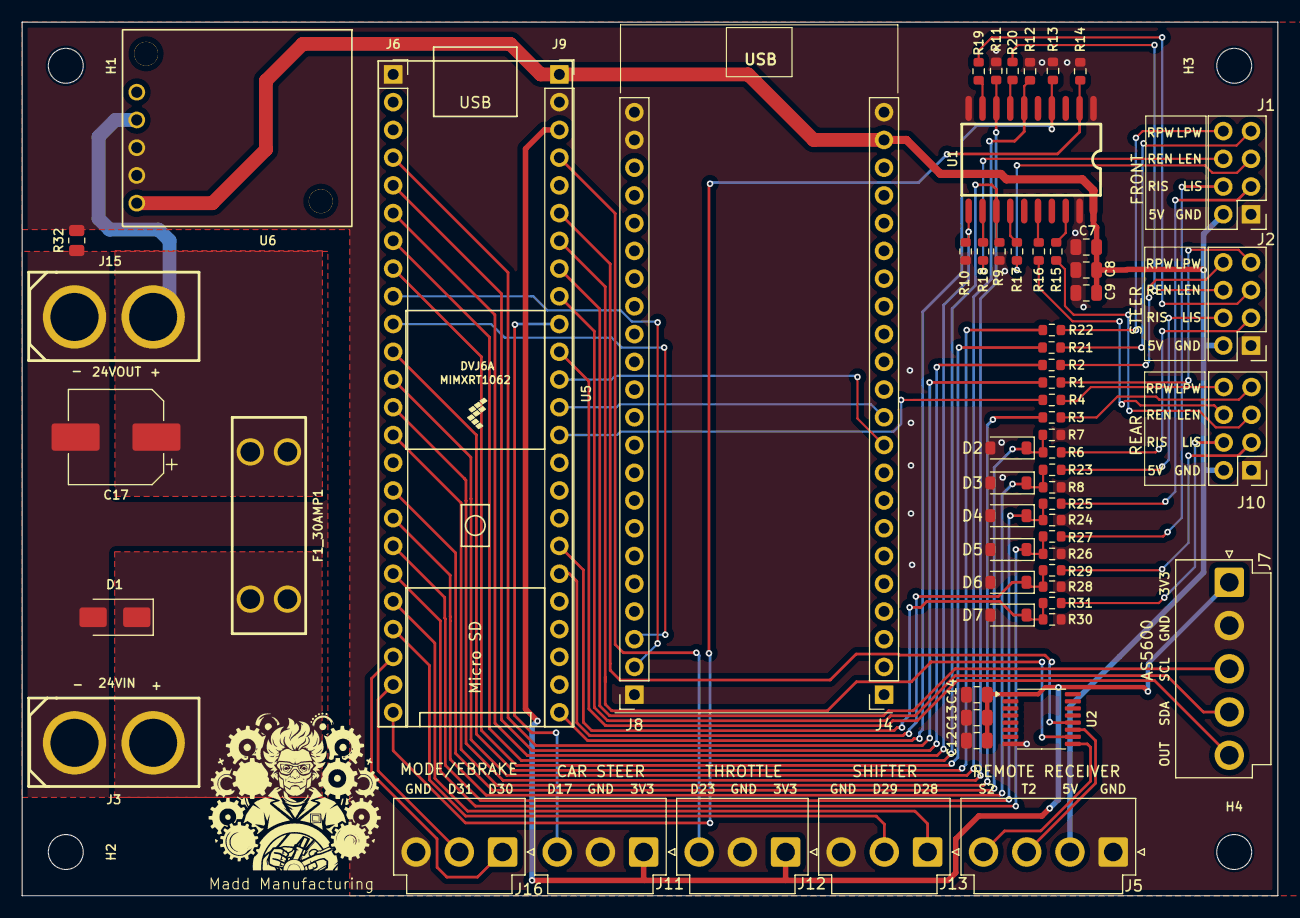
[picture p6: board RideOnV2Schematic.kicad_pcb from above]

Board: 2 copper layers, 115.0 x 80.0 mm, 69 parts (0 on the bottom side), 65 nets.

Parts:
C7, C12: 100nF; C_0805_2012Metric
C8, C13: 1uF; C_0805_2012Metric
C9, C14: 10uF; C_0805_2012Metric
C17: 220uF/35V; CP_Elec_8x10.5
D1: SMAJ33A; D_SMA
D2, D3, D4, D5, D6, D7: 3.4V; D_SOD-123
F1_30AMP1: Fuse; FUSE-TH_4P-L19.8-W6.7_3557-2
H1, H2, H3, H4: MountingHole; MountingHole_3.2mm_M3
J1, J2, J10: Conn_02x04_Odd_Even; PinHeader_2x04_P2.54mm_Vertical
J3, J15: XT60-M.; CONN-TH_XT60
J4, J8: Conn_01x22; PinSocket_1x22_P2.54mm_Vertical
J5: Conn_01x04; JST_VH_B4P-VH-B_1x04_P3.96mm_Vertical
J6, J9: Conn_01x24; PinSocket_1x24_P2.54mm_Vertical
J7: Conn_01x05; JST_VH_B5P-VH-B_1x05_P3.96mm_Vertical
J11, J12, J13, J16: Conn_01x03; JST_VH_B3P-VH-B_1x03_P3.96mm_Vertical
R1, R2, R3, R4, R15, R16, R17, R18, R19, R20, R21, R22: 33R; R_0603_1608Metric
R6, R23, R25, R27, R29, R31: 1.8k; R_0603_1608Metric
R7, R8, R24, R26, R28, R30: 3.3k; R_0603_1608Metric
R9, R10, R11, R12, R13, R14: 10k; R_0603_1608Metric
R32: 0R; R_0805_2012Metric
U1: SN74AHCT244; SOIC-20_L12.8-W7.5-P1.27-LS10.3-BL
U2: CD74HC4050; TSSOP-16_4.4x5mm_P0.65mm
U5: Teensy4.1; Teensy41
U6: D24V50F5

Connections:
+3.3V: C12.1, C13.1, C14.1, J7.1, J9.3, J11.1, J12.1, U2.1 (VCC)
+5V: C7.1, C8.1, C9.1, J1.2, J2.2, J4.21, J5.2, J9.1, J10.2, U1.20 (VCC), U6.5 (VOUT)
+24V: C17.1, F1_30AMP1.1, J15.2, U6.2 (VIN)
/24VIN: D1.1 (A1), F1_30AMP1.2, J3.2
/FRONT_L_IS: J1.3, R25.2
/FRONT_R_IS: J1.4, R27.2
/OUT: J7.5, J9.11
/PIN_2: J6.4, R1.1
/PIN_3: J6.5, R2.1
/PIN_4: J6.6, R10.1, U1.11 (2A1)
/PIN_5: J6.7, R9.1, U1.13 (2A2)
/PIN_6: J6.8, R21.1
/PIN_7: J6.9, J8.2
/PIN_8: J6.10, J8.3
/PIN_9: J6.11, R22.1
/PIN_10: J6.12, R12.1, U1.6 (1A3)
/PIN_11: J6.13, R11.1, U1.8 (1A4)
/PIN_12: J6.14, R3.1
/PIN_13: J9.14, R4.1
/PIN_14: J4.11, J9.13
/PIN_15: J4.10, J9.12
/PIN_17: J9.10, J11.3
/PIN_18: J7.4, J9.9
/PIN_19: J7.3, J9.8
/PIN_20: J9.7, U2.10
/PIN_21: J9.6, U2.12
/PIN_23: J9.4, J12.3
/PIN_24: D2.1 (K), J6.16, R6.1, R7.2
/PIN_25: D3.1 (K), J6.17, R8.2, R23.1
/PIN_26: D4.1 (K), J6.18, R24.2, R25.1
/PIN_27: D5.1 (K), J6.19, R26.2, R27.1
/PIN_28: J6.20, J13.1
/PIN_29: J6.21, J13.2
/PIN_30: J6.22, J16.1
/PIN_31: J6.23, J16.2
/PIN_32: J6.24, R14.1, U1.2 (1A1)
/PIN_33: J9.24, R13.1, U1.4 (1A2)
/PIN_38: D6.1 (K), J9.19, R28.2, R29.1
/PIN_39: D7.1 (K), J9.18, R30.2, R31.1
/PIN_FRONT_LEN: J1.5, R17.2
/PIN_FRONT_LPWM: J1.7, R21.2
/PIN_FRONT_REN: J1.6, R18.2
/PIN_FRONT_RPWM: J1.8, R22.2
/PIN_REAR_LEN: J10.5, R15.2
/PIN_REAR_LPWM: J10.7, R3.2
/PIN_REAR_REN: J10.6, R16.2
/PIN_REAR_RPWM: J10.8, R4.2
/PIN_STEER_LEN: J2.5, R19.2
/PIN_STEER_LPWM: J2.7, R1.2
/PIN_STEER_REN: J2.6, R20.2
/PIN_STEER_RPWM: J2.8, R2.2
/REAR_L_IS: J10.3, R29.2
/REAR_R_IS: J10.4, R31.2
/S2: J5.4, U2.9
/STEER_L_IS: J2.3, R6.2
/STEER_R_IS: J2.4, R23.2
/T2: J5.3, U2.11
GND: C7.2, C8.2, C9.2, C12.2, C13.2, C14.2, D2.2 (A), D3.2 (A), D4.2 (A), D5.2 (A), D6.2 (A), D7.2 (A), J1.1, J2.1, J4.22, J5.1, J6.1, J7.2, J8.1, J8.21, J8.22, J9.2, J10.1, J11.2, J12.2, J13.3, J16.3, R7.1, R8.1, R9.2, R10.2, R11.2, R12.2, R13.2, R14.2, R24.1, R26.1, R28.1, R30.1, R32.2, U1.1 (1OE), U1.10 (GND), U1.19 (2OE), U2.8 (GND), U6.3 (GND1), U6.4 (GND2)
GNDPWR: C17.2, D1.2 (A2), J3.1, J15.1, R32.1
unnamed: R15.1, U1.18 (1Y1)
unnamed: R16.1, U1.16 (1Y2)
unnamed: R17.1, U1.14 (1Y3)
unnamed: R18.1, U1.12 (1Y4)
unnamed: R19.1, U1.9 (2Y1)
unnamed: R20.1, U1.7 (2Y2)

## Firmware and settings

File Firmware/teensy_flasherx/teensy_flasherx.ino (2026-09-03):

/*******************************************************************************
 * Teensy 4.1 Kids Ride-On Controller
 * 
 * Main application code for controlling ride-on vehicle peripherals.
 * OTA firmware updates handled by FlasherXOTA module.
 * 
 * Serial Configuration (Custom PCB):
 *   Serial  (USB)    - Arduino IDE / Debug Console
 *   Serial2 (7/8)    - ESP32 Flash Serial (OTA updates)
 *   Serial3 (15/14)  - ESP32 Debug Serial / Telemetry
 ******************************************************************************/

#include <Arduino.h>
#include <Wire.h>
#include "FlasherXOTA.h"
#include "Telemetry.h"

//******************************************************************************
// Version Information
//******************************************************************************
#define FIRMWARE_VERSION "1.8.13"
#define BUILD_DATE       __DATE__ " " __TIME__

//******************************************************************************
//                    USER CONFIGURATION SECTION
//******************************************************************************
// Calibrate these values to match YOUR specific sensors and hardware.
// Use the serial monitor to read raw values, then enter your min/max here.
//******************************************************************************

// ----- STEERING POT (S1_WIPER) -----
// CALIBRATE THESE VALUES: Use serial monitor to read raw ADC values at each position
#define STEERING_POT_PIN      17      // Pin 17 (A3) - Steering potentiometer
#define STEERING_POT_MIN      105     // Raw ADC value at full LEFT (calibrate to your hardware)
#define STEERING_POT_MAX      708     // Raw ADC value at full RIGHT (calibrate to your hardware)
#define STEERING_POT_CENTER   407     // Raw ADC value at CENTER = (MIN+MAX)/2
#define STEERING_POT_DEADZONE 20      // Ignore values within +/- this of center
#define STEERING_INPUT_SMOOTH 15      // Ignore steering changes < this % to filter jitter
#define STEERING_FILTER_ALPHA 0.3     // Low-pass filter: 0.0-1.0 (lower = more filtering)

// ----- STEERING MOTOR LIMITS (Encoder Angle in Degrees) -----
// Keep the existing 0° steering-control coordinate system because it is proven on this car.
// The AS5600 telemetry remains offset so straight wheels display about 180°.
// Left travel is intentionally larger than right to reach the measured ~132° physical endpoint.
#define STEER_ANGLE_CENTER       0       // Existing steering-control center
#define STEER_ANGLE_RANGE        45      // Right-side command range: full right = 45°
#define STEER_LEFT_ANGLE_RANGE   52      // Left-side command range: full left = 308°
#define STEER_ANGLE_MIN          (360 - STEER_LEFT_ANGLE_RANGE)  // Full left command (308°)
#define STEER_ANGLE_MAX          STEER_ANGLE_RANGE               // Full right command (45°)
#define STEER_MOTOR_SPEED        100     // PWM speed for steering (0-255)
#define STEER_ANGLE_DEADBAND     15      // Preserve existing stop behavior

// ----- THROTTLE POT (T1_WIPER) -----
#define THROTTLE_POT_PIN      23      // Pin 23 (A9) - Throttle potentiometer
#define THROTTLE_POT_MIN      249     // Raw ADC value at NO throttle (foot off)
#define THROTTLE_POT_MAX      790     // Raw ADC value at FULL throttle
#define THROTTLE_POT_DEADZONE 30      // Ignore small values (prevents creep)

// ----- AS5600 MAGNETIC ENCODER (I2C ONLY) -----
#define ENCODER_I2C_ADDR      0x36    // Default AS5600 I2C address
#define ENCODER_CPR           4096    // Counts per revolution (12-bit = 4096)
#define ENCODER_VALID_READS_REQUIRED 3 // Require consecutive good reads before steering is enabled
#define ENCODER_FAULT_CONFIRM_FAILURES 3 // Consecutive failures required before latching a shutdown fault
#define ENCODER_FAULT_NO_DATA 6      // Application fault code: AS5600 transaction succeeded but angle bytes were missing
//
// HOW TO CALIBRATE ENCODER_ANGLE_OFFSET:
// 1. Set ENCODER_ANGLE_OFFSET to 0 temporarily
// 2. Upload firmware and open serial monitor
// 3. Steer wheels to STRAIGHT (center) position
// 4. Read the raw encoder angle displayed (e.g., 233°)
// 5. Calculate offset: ENCODER_ANGLE_OFFSET = (180 - raw_angle + 360) % 360
//    Example: If raw reads 233°, offset = (180 - 233 + 360) % 360 = 307
// 6. Set ENCODER_ANGLE_OFFSET to your calculated value
// 7. After upload, center should now display 180°
//
#define ENCODER_ANGLE_OFFSET  300     // Adjusted for physical steering arm mounting (+10°)

// ----- CURRENT SENSING -----
// All current sense pins output 0-3.3V proportional to motor current
#define STEER_CURRENT_L_PIN   24      // Pin 24 (A10) - Steering motor current Left
#define STEER_CURRENT_R_PIN   25      // Pin 25 (A11) - Steering motor current Right
#define FRONT_CURRENT_L_PIN   26      // Pin 26 (A12) - Front drive current Left
#define FRONT_CURRENT_R_PIN   27      // Pin 27 (A13) - Front drive current Right
#define REAR_CURRENT_L_PIN    38      // Pin 38 (A14) - Rear drive current Left
#define REAR_CURRENT_R_PIN    39      // Pin 39 (A15) - Rear drive current Right
#define CURRENT_SENSE_SCALE   1.0     // mV per Amp (adjust for your sensor)

// ----- RC RECEIVER INPUTS (0-3.3V) -----
#define RC_STEER2_PIN         21      // Pin 21 (A7) - RC Steering (steer2)
#define RC_THROTTLE2_PIN      20      // Pin 20 (A6) - RC Throttle (throttle2)

// ----- MOTOR CONFIGURATION -----
#define MOTOR_PWM_FREQ        20000   // PWM frequency in Hz
#define MOTOR_MAX_SPEED       255     // Maximum PWM value (0-255)
#define MOTOR_RAMP_RATE       5       // Speed change per loop (acceleration limit)

//******************************************************************************
//                    END USER CONFIGURATION
//******************************************************************************

//******************************************************************************
// Pin Definitions (Fixed by V2.1 PCB design - DO NOT CHANGE)
//******************************************************************************

// ===== ANALOG INPUTS (0-3.3V) =====
#define PIN_STEERING_POT      17      // A3  - Steering Pot (S1_WIPER)
#define PIN_THROTTLE_POT      23      // A9  - Throttle Pot (T1_WIPER)
#define PIN_STEER_CURRENT_L   24      // A10 - Steer Motor Current L
#define PIN_STEER_CURRENT_R   25      // A11 - Steer Motor Current R
#define PIN_FRONT_CURRENT_L   26      // A12 - Front Drive Current L
#define PIN_FRONT_CURRENT_R   27      // A13 - Front Drive Current R
#define PIN_REAR_CURRENT_L    38      // A14 - Rear Drive Current L
#define PIN_REAR_CURRENT_R    39      // A15 - Rear Drive Current R

// ===== DIGITAL INPUTS (3.3V Logic) =====
#define PIN_SHIFTER_FWD       29      // Shifter Forward (swapped)
#define PIN_SHIFTER_REV       28      // Shifter Reverse (swapped)
#define PIN_BRAKE_NC          30      // Brake microswitch NC contact
#define PIN_BRAKE_NO          31      // Brake microswitch NO contact

// ===== PWM OUTPUTS (3.3V) =====
#define PIN_STEER_LPWM        2       // Steering LPWM
#define PIN_STEER_RPWM        3       // Steering RPWM
#define PIN_FRONT_LPWM        6       // Front Drive LPWM
#define PIN_FRONT_RPWM        9       // Front Drive RPWM
#define PIN_REAR_LPWM         12      // Rear Drive LPWM
#define PIN_REAR_RPWM         13      // Rear Drive RPWM

// ===== MOTOR DRIVER ENABLE OUTPUTS (3.3V -> 5V via level shifter) =====
#define PIN_STEER_L_EN        4       // Steering L_EN
#define PIN_STEER_R_EN        5       // Steering R_EN
#define PIN_FRONT_L_EN        10      // Front Drive L_EN
#define PIN_FRONT_R_EN        11      // Front Drive R_EN
#define PIN_REAR_L_EN         32      // Rear Drive L_EN
#define PIN_REAR_R_EN         33      // Rear Drive R_EN

// ===== I2C (AS5600 Encoder) =====
#define PIN_I2C_SDA           18      // I2C Data
#define PIN_I2C_SCL           19      // I2C Clock

// ===== UART TO ESP32-S3 =====
// Serial2: OTA Firmware Updates
#define PIN_ESP_RX2           7       // Teensy RX2 <- ESP32 GPIO43 (TX)
#define PIN_ESP_TX2           8       // Teensy TX2 -> ESP32 GPIO44 (RX)
// Serial3: Debug/Monitoring
#define PIN_ESP_RX3           15      // Teensy RX3 <- ESP32 GPIO17 (TX)
#define PIN_ESP_TX3           14      // Teensy TX3 -> ESP32 GPIO18 (RX)

//******************************************************************************
// Configuration
//******************************************************************************
#define HEARTBEAT_INTERVAL 10000  // ms
#define LOOP_TIME_SMOOTHING 0.1   // EMA smoothing factor for loop time

// Soft start/stop configuration for drive motors
#define SOFT_START_RATE      2      // Percentage to increase per update cycle (lower = slower acceleration)
#define SOFT_START_INTERVAL  30     // Milliseconds between ramp-up steps
#define SOFT_STOP_RATE       1      // Percentage to decrease per update cycle (lower = slower deceleration)
#define SOFT_STOP_INTERVAL   30     // Milliseconds between ramp-down steps

// Dual-contact brake input + progressive dynamic braking
// Omron SPDT wiring: COM -> GND, NC -> D30, NO -> D31
// INPUT_PULLUP truth table:
//   D30 LOW,  D31 HIGH = released
//   D30 HIGH, D31 LOW  = pressed
//   D30 HIGH, D31 HIGH = invalid/open circuit
//   D30 LOW,  D31 LOW  = invalid/shorted wiring
#define BRAKE_FAULT_CONFIRM_MS       100
#define BRAKE_RAMP_MS                600
#define BRAKE_INITIAL_DUTY           25
#define BRAKE_MAX_DUTY               100
#define BRAKE_REARM_PEDAL_MAX        5
#define BRAKE_REARM_RC_MAX           10

// Rollover protection - limits throttle based on actual steering angle
// The sharper the turn (based on encoder), the more throttle is limited
#define ROLLOVER_STEER_THRESHOLD     20     // Steering angle % where throttle limiting begins (0-100)
#define ROLLOVER_MAX_THROTTLE_AT_FULL_STEER  40  // Max throttle % allowed at full steering (100%)
#define ROLLOVER_DEFAULT_ENABLED     false  // Default state on boot (can be toggled at runtime)

//******************************************************************************
// Global Variables
//******************************************************************************
uint32_t loopStartTime = 0;
uint32_t smoothedLoopTime = 0;

// RC Mode tracking
bool rcModeActive = false;           // Is RC mode currently active?
bool rcModePending = false;          // RC mode armed, waiting for neutral to fully activate
uint32_t throttleHoldStartTime = 0; // When did throttle go above threshold?

// Soft stop tracking for drive motors
int currentDriveSpeed = 0;           // Current actual motor speed (0-100)
int currentDriveDirection = 0;       // Current direction (0=OFF, 1=FWD, 2=REV)
uint32_t lastSoftStopTime = 0;       // Last time we did a ramp-down step

// Rollover protection state
bool rolloverProtectionEnabled = ROLLOVER_DEFAULT_ENABLED;  // Runtime enable/disable
int limitedSteeringPercent = 0;      // Steering % after speed-based limiting
int rolloverSpeedLimit = 100;        // Current speed limit due to steering angle
bool throttleHoldingHigh = false;   // Is throttle currently held high?
uint32_t lastRcInputTime = 0;       // Last time we got RC input (steer2 or throttle2)

// Steering encoder safety state. A single failed read disables steering immediately.
// Three consecutive failures latch the vehicle shutdown until reboot.
bool encoderValid = false;
uint8_t encoderGoodReadCount = 0;
uint8_t encoderFailureCount = 0;
bool encoderFaultLatched = false;
uint8_t encoderFaultCode = 0;

// Brake safety state
enum BrakeInputState : uint8_t {
    BRAKE_INPUT_RELEASED = 0,
    BRAKE_INPUT_PRESSED  = 1,
    BRAKE_INPUT_INVALID  = 2
};

BrakeInputState brakeInputState = BRAKE_INPUT_INVALID;
bool brakeNcClosed = false;
bool brakeNoClosed = false;
bool brakeCommandActive = false;
bool brakeFaultLatched = false;
bool brakeRearmRequired = false;
bool brakeInvalidTiming = false;
bool brakeOutputsActive = false;
uint32_t brakeInvalidStartTime = 0;
uint32_t brakeCommandStartTime = 0;
uint8_t currentBrakeDuty = 0;

// Serial command buffer for ESP32 commands
char cmdBuffer[64];
int cmdBufferIndex = 0;

// Preserve the proven center/right steering coordinate system while allowing
// a larger left command range. This keeps motor direction and center behavior unchanged.
int steeringTargetFromPercent(int steeringPercent) {
    steeringPercent = constrain(steeringPercent, -100, 100);
    int targetAngle;
    if (steeringPercent < 0) {
        targetAngle = (steeringPercent * STEER_LEFT_ANGLE_RANGE) / 100;
    } else {
        targetAngle = (steeringPercent * STEER_ANGLE_RANGE) / 100;
    }
    if (targetAngle < 0) {
        targetAngle += 360;
    }
    return targetAngle;
}

//******************************************************************************
// setup()
//******************************************************************************
void setup() {
    // Initialize USB Serial for debugging
    Serial.begin(115200);
    delay(1000);
    
    // Initialize communication serials
    Serial2.begin(115200);  // ESP32 Flash Serial
    Serial3.begin(115200);  // ESP32 Debug/Telemetry Serial
    
    // Print startup banner
    Serial.println("\n========================================");
    Serial.println("   Kids Ride-On Controller - Teensy 4.1");
    Serial.println("========================================");
    Serial.printf("Firmware: %s\n", FIRMWARE_VERSION);
    Serial.printf("Build:    %s\n", BUILD_DATE);
    Serial.println();
    
    // Initialize OTA update system
    OTA.begin(&Serial2, &Serial3, &Serial, FIRMWARE_VERSION, BUILD_DATE);
    
    // Initialize I2C for AS5600 encoder
    Wire.begin();
    Wire.setClock(400000);  // 400 kHz I2C speed
    Serial.println("I2C Initialized for AS5600 encoder (400 kHz)");
    
    // Restore the normal startup bus scan. The AS5600 register probe remains disabled.
    delay(100);
    scanI2CBus();
    delay(100);
    
    // Initialize telemetry (sends to ESP32 via Serial3)
    Telem.begin(&Serial3, &Serial);
    Telem.setInterval(100);  // 100ms = 10Hz update rate
    Telem.setCompactMode(true);
    
    // Initialize peripherals
    initPeripherals();
    
    // Notify ESP32 we're ready
    Serial3.printf("Teensy v%s ready\n", FIRMWARE_VERSION);
    
    Serial.println("\nCommands: 'update', 'version', 'status', 'telem', 'header'");
    Serial.println("Ready.\n");
}

//******************************************************************************
// setSteeringMotor() - Control steering motor based on steering input
// steeringPercent: -100 to +100 (-100=full left, +100=full right)
// calibrationMode: if true, use reduced speed for calibration
//******************************************************************************
void setSteeringMotor(int steeringPercent, bool calibrationMode = true) {
    // Calibration mode: slow speed (20/255 ≈ 8%) for precise control
    // Normal mode: full speed (255)
    int maxSpeed = calibrationMode ? 20 : MOTOR_MAX_SPEED;
    
    // Convert percentage to PWM value
    // steeringPercent ranges from -100 to +100
    int pwmValue = (abs(steeringPercent) * maxSpeed) / 100;
    
    // Clamp to max
    if (pwmValue > maxSpeed) pwmValue = maxSpeed;
    
    // Enable both steering motor drivers
    digitalWrite(PIN_STEER_L_EN, HIGH);
    digitalWrite(PIN_STEER_R_EN, HIGH);
    
    if (steeringPercent > 5) {
        // Steer RIGHT: drive right PWM, left PWM off
        analogWrite(PIN_STEER_RPWM, pwmValue);
        analogWrite(PIN_STEER_LPWM, 0);
    } else if (steeringPercent < -5) {
        // Steer LEFT: drive left PWM, right PWM off
        analogWrite(PIN_STEER_LPWM, pwmValue);
        analogWrite(PIN_STEER_RPWM, 0);
    } else {
        // CENTERED: all PWM off
        analogWrite(PIN_STEER_LPWM, 0);
        analogWrite(PIN_STEER_RPWM, 0);
    }
}
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
void loop() {
    loopStartTime = micros();
    
    // Check for OTA update commands from ESP32
    OTA.checkForCommands();
    
    // Handle USB serial commands
    handleSerialCommands();
    
    // Handle ESP32 debug serial commands (Serial3)
    processEsp32Commands();
    
    // Read all inputs and update telemetry data
    readInputs();
    
    // Run peripheral control logic
    updatePeripherals();
    
    // Calculate loop time and update telemetry
    uint32_t loopTime = micros() - loopStartTime;
    smoothedLoopTime = (LOOP_TIME_SMOOTHING * loopTime) + ((1.0 - LOOP_TIME_SMOOTHING) * smoothedLoopTime);
    Telem.data().loopTimeUs = smoothedLoopTime;
    Telem.data().cpuTemp = tempmonGetTemp();  // Teensy 4.1 internal temp
    
    // Send telemetry (respects interval setting)
    Telem.update();
    
    // Debug output every 1 second
    static unsigned long lastDebug = 0;
    if (millis() - lastDebug >= 1000) {
        lastDebug = millis();
        
        TelemetryData& td = Telem.data();
        int targetAngle = steeringTargetFromPercent(td.steeringPercent);
        
        int angleError = targetAngle - td.encoderAngle;
        if (angleError > 180) angleError -= 360;
        else if (angleError < -180) angleError += 360;
        
        Serial.printf("Steer1: %3d%% | Current: %3d° | Target: %3d° | Error: %4d° | PWM: L=%3d R=%3d\n",
                     td.steeringPercent, td.encoderAngle, targetAngle, angleError,
                     td.steerPwmL, td.steerPwmR);
        Serial.printf("Throttle1: %3d%% | Steer2: %3d%% (raw=%4d) | Throttle2: %3d%% (raw=%4d) | RC Mode: %s\n",
                     td.throttlePercent, td.steer2Percent, td.steer2Raw, td.throttle2Percent, td.throttle2Raw,
                     rcModeActive ? "ACTIVE" : "inactive");
        Serial.printf("Brake: %s | NC=%d NO=%d | Duty=%3d%% | Fault=%s | Rearm=%s\n",
                     brakeCommandActive ? "ACTIVE" : "off",
                     brakeNcClosed ? 1 : 0,
                     brakeNoClosed ? 1 : 0,
                     currentBrakeDuty,
                     brakeFaultLatched ? "LATCHED" : "none",
                     brakeRearmRequired ? "WAIT_NEUTRAL" : "ready");
    }
    
    // Heartbeat (for ESP32 connection monitoring)
    heartbeat();
}

//******************************************************************************
// scanI2CBus() - Scan for I2C devices on the bus
//******************************************************************************
void scanI2CBus() {
    Serial.println("\n=== I2C Bus Scan ===");
    delay(500);  // Give time to see the header
    int found = 0;
    
    for (byte addr = 1; addr < 127; addr++) {
        Wire.beginTransmission(addr);
        byte error = Wire.endTransmission();
        
        if (error == 0) {
            Serial.printf("  [0x%02X] Device found\n", addr);
            delay(100);  // Slow down output so it's readable
            found++;
            
            // The old AS5600 register probe stays disabled. It is not required
            // for normal operation and should remain separate from the safety path.
            if (addr == ENCODER_I2C_ADDR) {
                delay(200);
                // probeAS5600();
                delay(200);
            }
        }
    }
    
    delay(300);
    if (found == 0) {
        Serial.println("  NO DEVICES FOUND on I2C bus!");
        Serial.println("  CHECK: SDA/SCL connections, pull-ups, power supply");
    } else {
        Serial.printf("  Total: %d device(s)\n", found);
    }
    Serial.println();
    delay(500);
}

//******************************************************************************
// probeAS5600() - Read AS5600 registers and display raw values
//******************************************************************************
void probeAS5600() {
    Serial.println("\n--- AS5600 Register Probe ---");
    
    // Read status register (0x02)
    Wire.beginTransmission(ENCODER_I2C_ADDR);
    Wire.write(0x02);
    Wire.endTransmission();
    Wire.requestFrom(ENCODER_I2C_ADDR, 1);
    
    if (Wire.available()) {
        uint8_t status = Wire.read();
        Serial.printf("  Status Reg (0x02): 0x%02X\n", status);
        Serial.printf("    MagnetDetected: %s\n", (status & 0x20) ? "NO" : "YES");
        Serial.printf("    MagnetTooWeak:  %s\n", (status & 0x10) ? "YES" : "NO");
        Serial.printf("    MagnetTooStrong:%s\n", (status & 0x08) ? "YES" : "NO");
    } else {
        Serial.println("  ERROR: Cannot read Status register");
        return;
    }
    
    // Read angle registers (0x0E = MSB, 0x0F = LSB)
    Wire.beginTransmission(ENCODER_I2C_ADDR);
    Wire.write(0x0E);
    Wire.endTransmission();
    Wire.requestFrom(ENCODER_I2C_ADDR, 2);
    
    if (Wire.available() >= 2) {
        uint16_t rawAngle = (Wire.read() << 8) | Wire.read();
        uint16_t angleDeg = (rawAngle * 360) / 4096;
        Serial.printf("  Angle Raw (0x0E/0x0F): %4d counts = %3d degrees\n", rawAngle, angleDeg);
    } else {
        Serial.println("  ERROR: Cannot read Angle registers");
    }
    
    Serial.println();
}

//******************************************************************************
// Encoder fault helpers
//******************************************************************************
void latchEncoderFault(uint8_t code) {
    if (encoderFaultLatched) {
        return;
    }

    encoderFaultLatched = true;
    encoderFaultCode = code;
    encoderValid = false;
    encoderGoodReadCount = 0;
    currentDriveSpeed = 0;
    currentDriveDirection = 0;

    allMotorsOff();

    Serial.printf("[FAULT] ENCODER %u LATCHED - all motor outputs disabled until reboot\n", code);
    Serial3.printf("FAULT:ENCODER:%u\n", code);
}

void noteEncoderFailure(uint8_t code) {
    // Never steer from a failed/stale read, even before the fault is confirmed.
    encoderValid = false;
    encoderGoodReadCount = 0;

    if (encoderFaultLatched) {
        return;
    }

    if (encoderFailureCount < 255) {
        encoderFailureCount++;
    }

    if (encoderFailureCount >= ENCODER_FAULT_CONFIRM_FAILURES) {
        latchEncoderFault(code);
    }
}
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

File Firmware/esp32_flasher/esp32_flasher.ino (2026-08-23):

/*
 * ESP32-S3 Teensy 4.1 FlasherX Web Interface
 * 
 * Custom PCB Pin Configuration:
 * - Flashing: ESP32 TX0/RX0 (GPIO43/44) ↔ Teensy Serial2 (Pin 7/8)
 * - Debug:    ESP32 GPIO17/18 ↔ Teensy Serial3 (Pin 14/15)
 * 
 * Features:
 * - Web server at (see serial monitor at 115200 for ip address) for firmware uploads
 * - FlasherX protocol for Teensy 4.1 programming
 * - OTA updates for ESP32 itself
 * - Upload progress bar and error reporting
 * - Serial monitoring via WebSocket
 */

#include <WiFi.h>
#include <WebServer.h>
#include <Update.h>
#include <ArduinoJson.h>
#include <WebSocketsServer.h>
#include "secrets.h"

// WiFi credentials loaded from secrets.h
// Copy secrets.h.example to secrets.h and add your credentials
const char* ssid = WIFI_SSID;
const char* password = WIFI_PASSWORD;
// Using DHCP - static IP should be set on your router if needed

// ============================================
// Version Information
// ============================================
#define ESP_FIRMWARE_VERSION "1.2.8"
#define ESP_BUILD_DATE __DATE__ " " __TIME__
String teensyVersion = "Unknown";

// ============================================
// Custom PCB UART Pin Configuration
// ============================================

// Flashing UART: ESP32 UART1 (GPIO43/44) ↔ Teensy Serial2 (Pin 7/8)
// Used for firmware upload via FlasherX protocol
#define TEENSY_FLASH_SERIAL Serial1
#define TEENSY_FLASH_TX_PIN 43  // ESP32 TX → Teensy RX2 (Pin 7)
#define TEENSY_FLASH_RX_PIN 44  // ESP32 RX ← Teensy TX2 (Pin 8)

// Debug/Monitor UART: ESP32 UART2 (GPIO17/18) ↔ Teensy Serial3 (Pin 14/15)
// Used for serial monitoring and debug output
#define TEENSY_DEBUG_SERIAL Serial2
#define TEENSY_DEBUG_TX_PIN 17  // ESP32 TX → Teensy RX3 (Pin 15)
#define TEENSY_DEBUG_RX_PIN 18  // ESP32 RX ← Teensy TX3 (Pin 14)

// Control pins for Teensy reset/program mode
#define TEENSY_RESET_PIN 4
#define TEENSY_PROGRAM_PIN 5

// RGB LED on pin 38 (WS2812/NeoPixel style on ESP32-S3)
#define RGB_LED_PIN 38

// ============================================
// FlasherX protocol constants
// ============================================
#define FLASHERX_SYNC 0x55
#define FLASHERX_ACK 0x06
#define FLASHERX_NAK 0x15
#define FLASHERX_BLOCK_SIZE 256
#define FLASHERX_TIMEOUT_MS 5000
#define CMD_PING 0x03
#define CMD_VERSION 0x04
#define CMD_UPDATE 0x05

// Web server and WebSocket
WebServer server(80);
WebSocketsServer webSocket(81);

// Timing for Teensy detection
unsigned long lastTeensyPing = 0;
#define TEENSY_PING_INTERVAL 5000

// Upload state
bool uploadInProgress = false;
size_t uploadedBytes = 0;
size_t totalBytes = 0;
String uploadError = "";
bool teensyConnected = false;
bool espUpdating = false;
bool teensyUpdating = false;

// RGB LED state
enum LedState {
    LED_OFF,
    LED_RED,           // Not connected
    LED_GREEN,         // Connected, no heartbeat
    LED_GREEN_PULSE,   // Connected with heartbeat
    LED_BLUE_PULSE,    // Updating
    LED_YELLOW_CODE    // Latched encoder fault: blink fault number, then pause
};
LedState currentLedState = LED_OFF;
unsigned long lastHeartbeat = 0;
unsigned long lastLedUpdate = 0;
uint8_t ledBrightness = 0;
bool ledBrightnessUp = true;
#define HEARTBEAT_TIMEOUT 15000  // 15 seconds without heartbeat = no pulse
#define LED_PULSE_SPEED 10       // ms between brightness changes

// Encoder fault indication received from Teensy
bool encoderFaultActive = false;
uint8_t encoderFaultCode = 0;
unsigned long encoderFaultBlinkStart = 0;
#define FAULT_BLINK_ON_MS   250
#define FAULT_BLINK_OFF_MS  250
#define FAULT_BLINK_PAUSE_MS 2000

// Serial buffer for monitoring
#define SERIAL_BUFFER_SIZE 4096
char serialBuffer[SERIAL_BUFFER_SIZE];
int serialBufferIndex = 0;
int g_hexLineCount = 0;  // Global hex line counter

// Forward declarations
void handleRoot();
void handleTeensyUpload();
void handleEsp32Ota();
void handleStatus();
void handleTeensyReset();
void webSocketEvent(uint8_t num, WStype_t type, uint8_t* payload, size_t length);
bool flasherXSync();
bool flasherXSendBlock(uint8_t* data, size_t len, uint32_t address);
bool flasherXFinish();
void broadcastSerial(const char* msg);
void logMessage(const char* msg);
bool pingTeensy();
void requestTeensyVersion();
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

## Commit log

2025-12-24 Initial commit: Kids Ride-On Framework v1.3.0 - ESP32-S3 + Teensy 4.1 OTA system with telemetry
    [BOM-RideOnV2Schematic.csv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]
2026-08-23 Add encoder-valid startup steering gate
2026-08-23 Disable AS5600 startup probe for isolation test
2026-08-23 Disable startup I2C scan for AS5600 isolation test
2026-08-23 Add latched encoder fault safety shutdown
2026-08-23 Add yellow encoder fault blink codes
2026-08-24 Prepare steering calibration update
2026-08-24 Remove temporary steering calibration marker
2026-08-24 Extend left steering travel without changing center/right behavior
    Preserve the existing steering coordinate system, motor direction, center behavior, and right travel. Increase only the left-side steering command range from 45° to 52°, moving the effective full-lef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
2026-09-03 Add redundant progressive dynamic brake input

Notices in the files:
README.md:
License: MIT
